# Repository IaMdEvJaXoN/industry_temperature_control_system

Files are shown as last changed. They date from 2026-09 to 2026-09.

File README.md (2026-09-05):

# Industrial Temperature Monitor

A complete, full-stack engineering project encompassing Firebase Real Time Database,custom printed circuit board (PCB) design, embedded C++ firmware ,simulations and a Flutter mobile application. 

The system provides closed-loop temperature monitoring and PWM hardware actuation, synchronized globally with sub-second latency via Firebase Realtime Database (RTDB).

## System Architecture

The project is structured as a monolithic repository integrating three distinct engineering domains:

    industry_temperature_control/
    ├── hardware/     # KiCad EDA (Schematics, PCB layout, Gerbers)
    ├── firmware/     # PlatformIO C++ (ESP32 logic, RTDB sync)
    ├── software/     # Flutter Mobile App (Clean Architecture, Riverpod, Hive)
    └── docs/         # System architecture, renders,wokwi simulation and media assets

### High-Level Topology
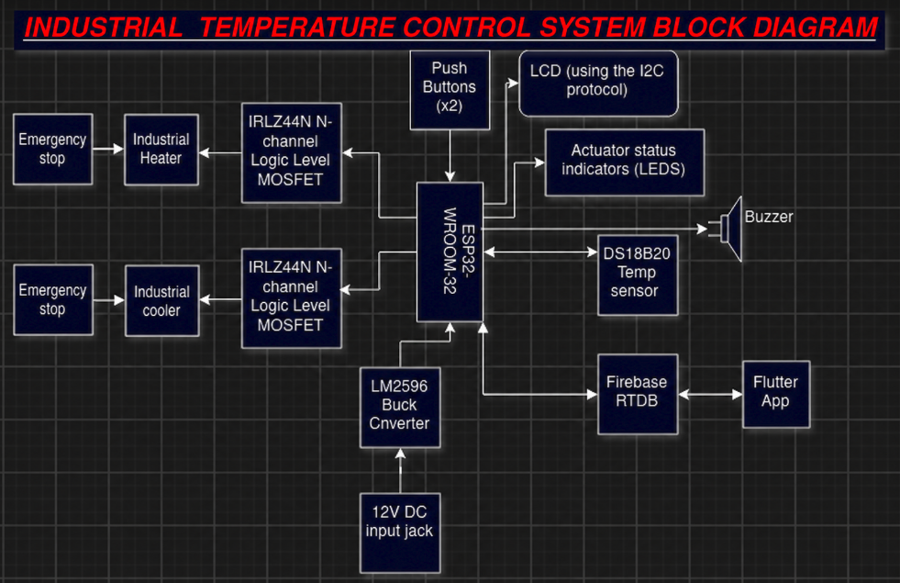
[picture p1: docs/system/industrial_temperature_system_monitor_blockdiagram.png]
System Block Diagram


*Validation: Real-time synchronization between the ESP32 hardware simulation and the Firebase RTDB backend.*
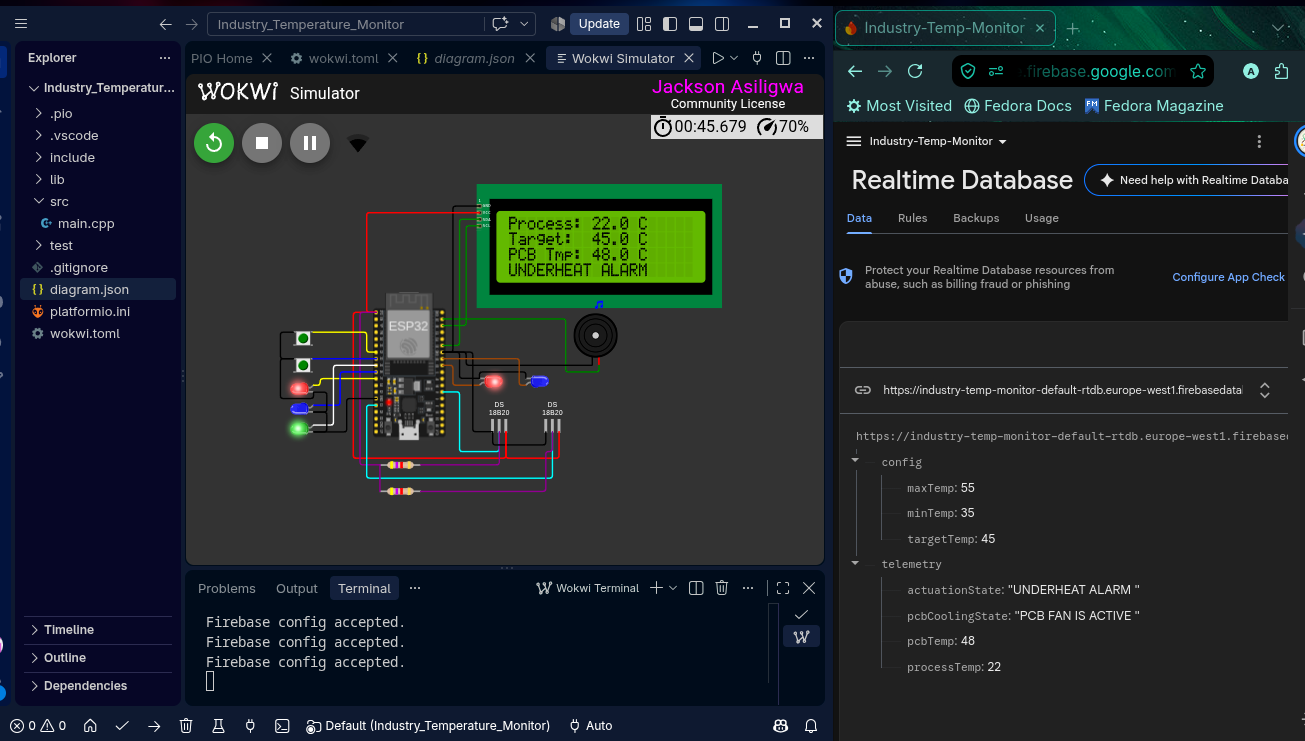
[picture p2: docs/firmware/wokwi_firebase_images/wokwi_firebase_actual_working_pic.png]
Wokwi Firebase Integration


---

## Hardware (KiCad)
The physical controller is a custom 2-layer PCB designed to handle both high-current 12V industrial loads and sensitive 3.3V digital logic.

**Core Specifications:**
* **Microcontroller:** DOIT ESP32 DEVKIT V1 -30 pin
* **Power Delivery Network (PDN):** 12V main input, regulated to 5V via an onboard LM2596 Buck Converter. High-current traces routed at 0.8mm width.
* **Logic Level Translation:** BOB-12009 bidirectional shifter (5V ↔ 3.3V) for I2C LCD communication.
* **Sensors & Actuators:** DS18B20 (1-Wire) digital temperature sensor, with MOSFET-driven PWM outputs for external fans and heating lamps.
* **Trace Topology:** 0.4mm logic lines routing across Top/Bottom copper planes with continuous ground pours for EMI shielding.

<p align="center">
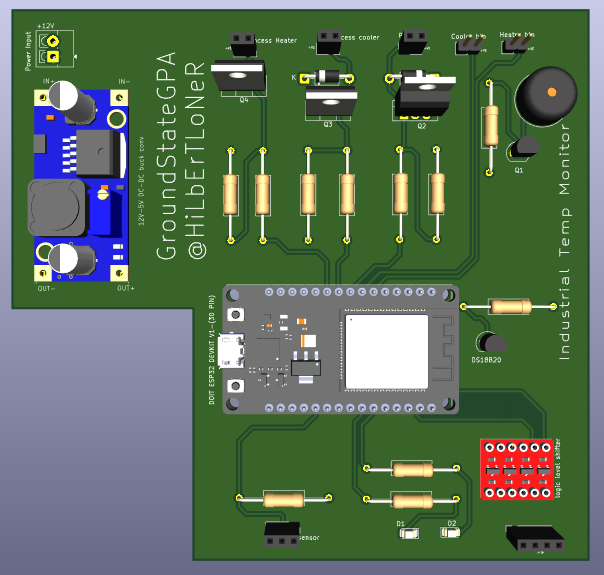
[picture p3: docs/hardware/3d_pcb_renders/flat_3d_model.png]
PCB Top Render
  
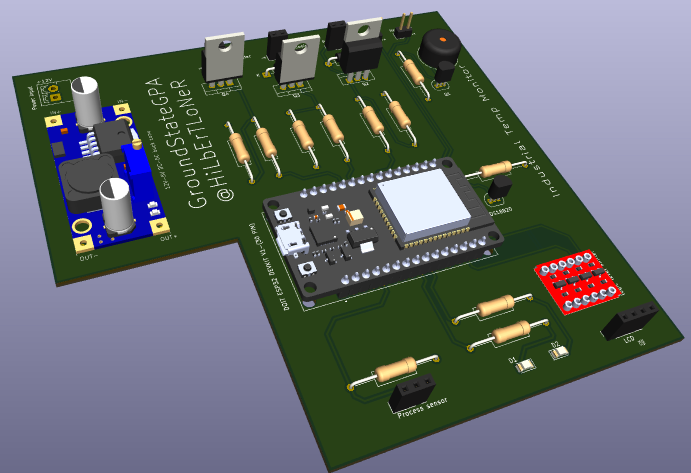
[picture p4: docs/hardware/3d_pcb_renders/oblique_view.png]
PCB Bottom Render
  
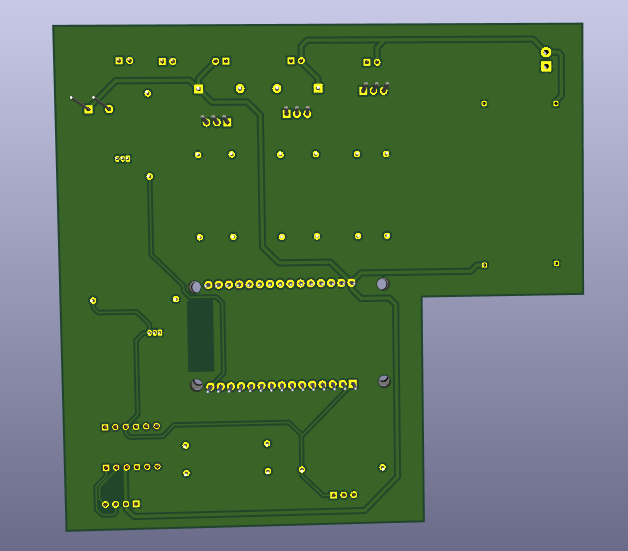
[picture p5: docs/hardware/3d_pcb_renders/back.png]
PCB Bottom Render
  
</p>

---

## Firmware (PlatformIO & Wokwi)
Written in C++ for the ESP32, the firmware manages real-time hardware interrupts, sensor polling, and network communication. 

**Key Features:**
* **Hardware Debouncing:** 200ms software debouncing for mechanical inputs.
* **Delta-Driven Telemetry:** Pushes raw JSON string payloads to the `/telemetry` RTDB node to minimize bandwidth (Tracking `processTemp`, `pcbTemp`, `actuationState`, and `pcbCoolingState`).
* **Config Listener:** Subscribes to the `/config` RTDB node to dynamically update operational setpoints (Target, Max, Min limits) pushed from the mobile app.

### Hardware Simulation
*A live capture of the logic execution in Wokwi:*

Hardware Simulation

---

## Software (Flutter Mobile App)
A mobile frontend built for performance.

**Technical Stack & Architecture:**
* **Architecture:** Strict Clean Architecture (Data, Domain, Presentation layers) utilizing Domain Use Cases to enforce boundary separation.
* **State Management:** Fully manual Riverpod (`AsyncNotifier` and `StreamProvider`), ensuring memory-safe stream disposal without code generation overhead.
* **Data Layer:** Direct Firebase RTDB streams (zero FCM/push notifications) for real-time telemetry, and Hive local storage mapping raw strings for history logging.
* **UI/UX:** Custom state-based routing, dynamic implicit animations driven by hardware states, and a Vantablack/charcoal design system.

<p align="center">
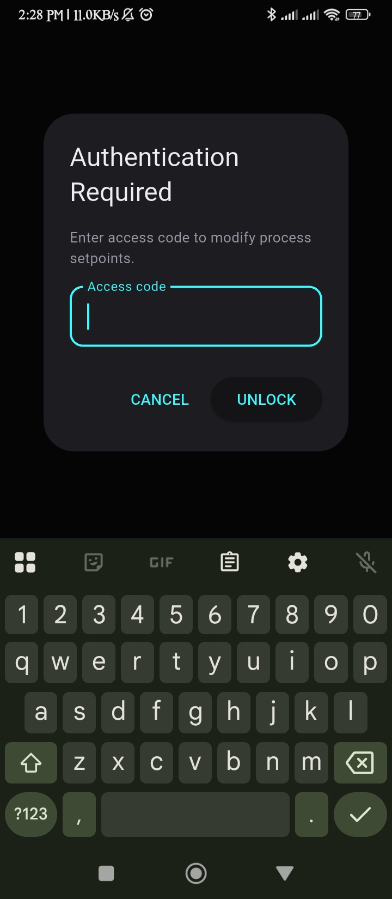
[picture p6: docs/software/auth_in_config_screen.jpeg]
Telemetry Dashboard
  
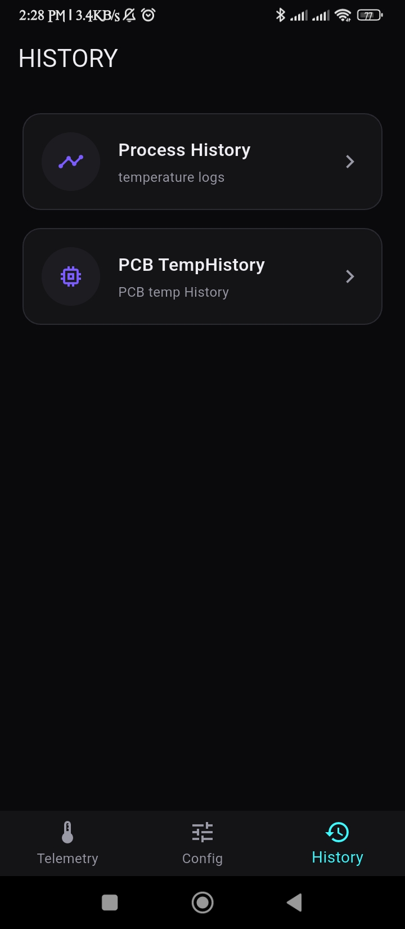
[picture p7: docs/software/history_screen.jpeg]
Configuration Hub
  
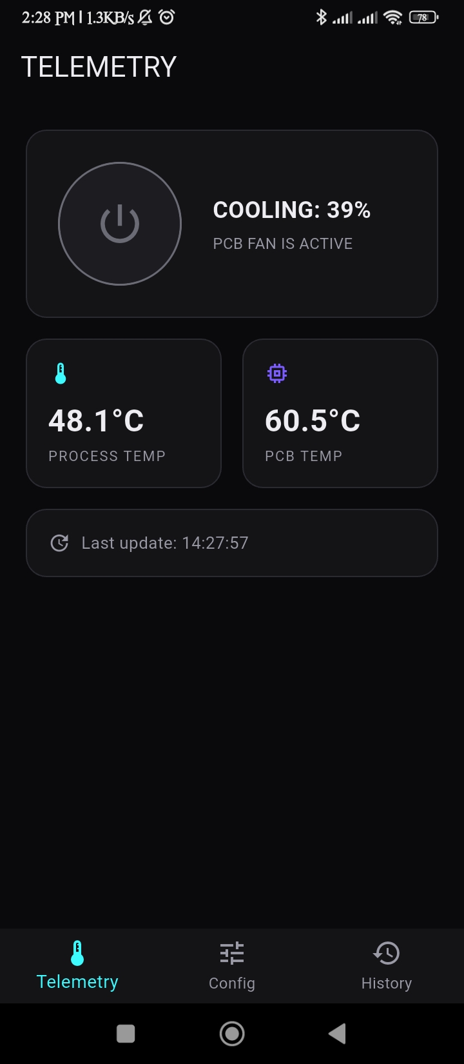
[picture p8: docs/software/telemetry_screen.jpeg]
History Logs
  
</p>

---

## Getting Started

**To view the Hardware:**
1. Install KiCad 10.0+.
2. Open `hardware/industry_temperature_control.kicad_pro`.

**To compile the Firmware:**
1. Open the `firmware/` directory in VS Code with the PlatformIO extension installed.
2. Create your firebase project and manually add your database URL and API_KEY-I removed mine for security purposes.
3. Build the environment to pull the required C++ dependencies.

**To run the Mobile App:**
1. Navigate to the `software/` directory.
2. Use your own firebase URL,the RTDB structure is already defined in the README.md of the software folder,you only need to create the Firebase project and create the nodes as they appear in the README.md in the software folder.
3. Run `flutterfire configure` command to configure your flutter app to the Firebase project.
4. Run `flutter pub get`.
5. Provide your own `google-services.json` (Android) from your Firebase console.
6. Run `flutter run`.

---
*Designed and engineered by Jackson Asiligwa*

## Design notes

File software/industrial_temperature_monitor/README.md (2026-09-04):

# Industrial Temperature Monitor

This flutter application is built for observing and configuring an industrial temperature control system. It presents live process and PCB temperatures, reports the controller's actuation state, and lets an authorised operator update temperature setpoints(the defined target,min and max operating point for a particular process e.g drying cereals or operating points for a machine like an industrial motor)  through Firebase Realtime Database.

## Features

- Live dashboard for process temperature, PCB temperature, controller actuation state, and PCB cooling status.
- Visual heating and cooling indicator with state-specific animation.
- Password-gated configuration form for target, minimum, and maximum temperatures.
- Input validation that requires `minimum < target < maximum` before writing configuration to the controller.
- Separate process and PCB history views backed by local Hive storage.
- Dark, operator-focused Material interface with Riverpod-managed state and stream lifecycles.

## How it works

The app subscribes to Firebase Realtime Database and maps the following nodes into the UI:

| Node | Fields | Purpose |
| --- | --- | --- |
| `/telemetry` | `processTemp`, `pcbTemp`, `actuationState`, `pcbCoolingState` | Live readings and controller state published by the ESP32. |
| `/config` | `target`, `min`, `max` | Operator setpoints written by the app after validation. |

The Firebase repository exposes these nodes as Dart streams. Riverpod providers consume the streams and rebuild only the affected screens. Hive is initialised at startup and supplies two local boxes for process and PCB history entries.

## Architecture

The app is built using flutter clean architecture principles.

## Technology

- Flutter and Dart (Dart SDK constraint: `^3.12.2`)
- `flutter_riverpod` for state management
- Firebase Core and Firebase Realtime Database for remote telemetry/configuration
- Hive/Hive Flutter for local history persistence
- Material Design

## Getting started

### Prerequisites

- A Flutter SDK compatible with the Dart constraint in [`pubspec.yaml`](pubspec.yaml)
- A Firebase Realtime Database configured with the schema above
- A controller or simulator that publishes telemetry to the configured database

### Run locally

```bash
flutter pub get
flutter run
```

The included FlutterFire configuration defines Firebase options for Android, iOS, macOS, web, and Windows. 

## Controller integration

An ESP32 or other controller must publish telemetry values that are numeric or numeric strings. Example:

```json
{
  "telemetry": {
    "processTemp": 72.4,
    "pcbTemp": 41.8,
    "actuationState": "COOLING",
    "pcbCoolingState": "FAN ON"
  },
  "config": {
    "target": 70.0,
    "min": 65.0,
    "max": 75.0
  }
}
```

## Security and operational notes

- The configuration gate is a demo convenience only. Its access code is embedded in the client and is **not** real access control.
- Do not rely on the app to protect process setpoints.THis is a demo app ,much better security configurations can be implemented.
- Firebase configuration files identify the project but do not implement database authorisation; verify database rules and authorised application identities separately.
- This application is a monitoring/configuration client, not a safety controller. Hardware failsafes, sensor validation, actuator limits, alarms, and emergency shutdown behaviour are implemented on the ESP32 side i.e in an actual industrial room.

Run the application against a controlled database/device before using it with real equipment. A successful UI connection or simulation does not establish electrical or thermal safety.

## License
The app is simply for development purposes,any contributions can be made.

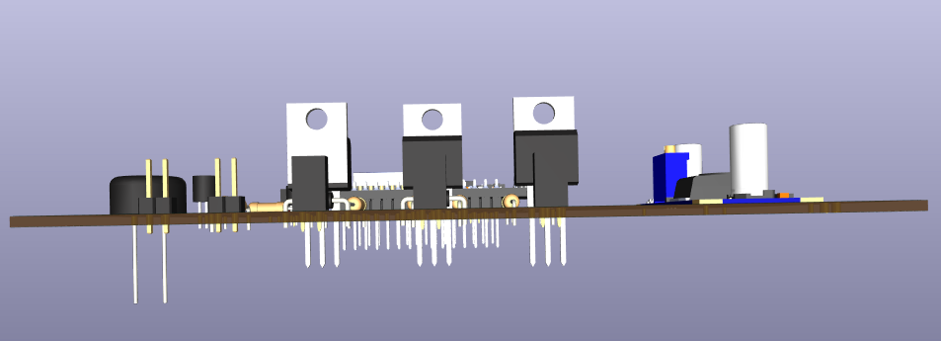
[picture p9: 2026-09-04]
docs/hardware/3d_pcb_renders/side_view.png

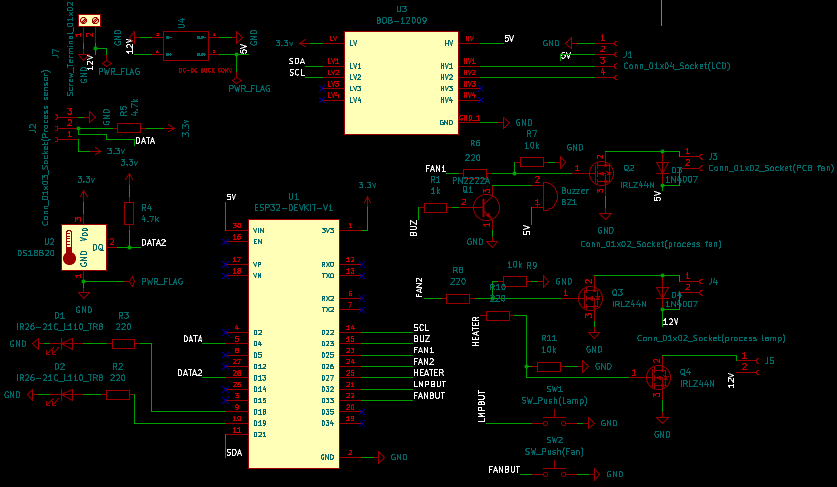
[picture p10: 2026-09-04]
docs/hardware/schematic/kicad_schematic.png

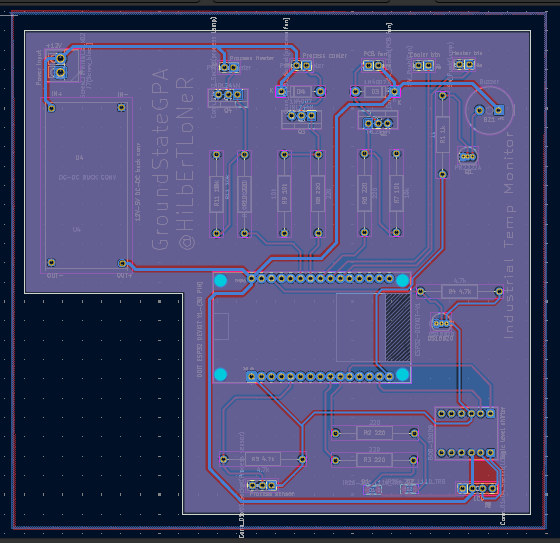
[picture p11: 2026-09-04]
docs/hardware/2d_pcb_images/back_copper_pcb.png

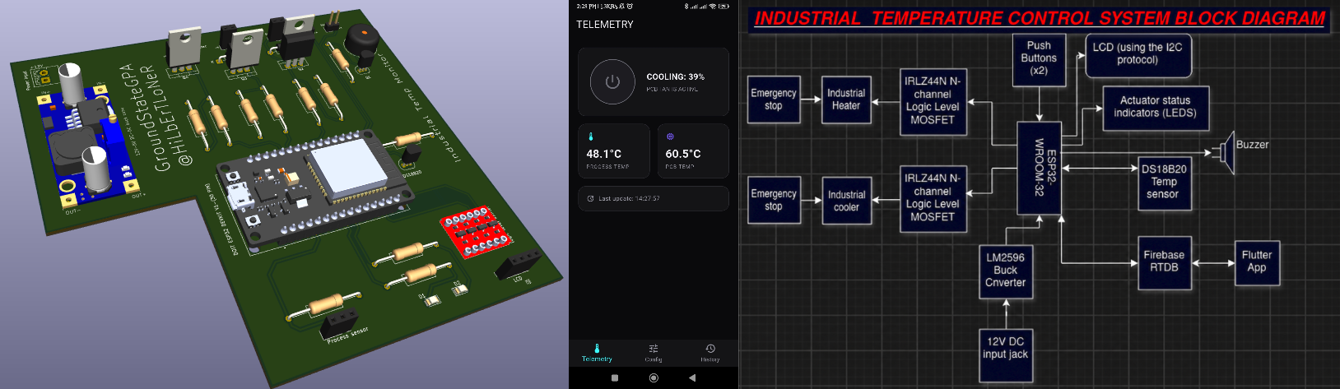
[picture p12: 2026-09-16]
docs/system/temp_monitor.png

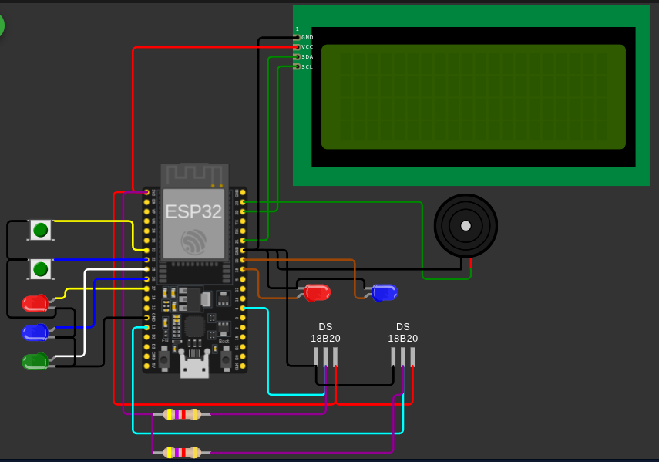
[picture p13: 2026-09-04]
docs/firmware/wokwi_firebase_images/wokwi_simulation.png

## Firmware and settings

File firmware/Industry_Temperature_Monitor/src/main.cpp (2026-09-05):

// LIBRARIES & DEPENDENCIES
#include <Arduino.h>             // The core Arduino framework functions(digitalWrite, millis, etc.)
#include <WiFi.h>                // Allows the ESP32 to connect to WIFI(local WiFi or Wokwi guest for simulation)
#include <Wire.h>                // I2C communication library (used to talk to the LCD screen)-enables the hardware communication
#include <OneWire.h>             // The low-level protocol required to talk to Dallas temperature sensors
#include <DallasTemperature.h>   // Translates the raw OneWire data into human-readable degree celsius values
#include <PID_v1.h>              // The PID engine is provided by this library.The calculus library that calculates smooth heating curves
#include <LiquidCrystal_I2C.h>   // Controls the 20x4 character display over I2C
#include <Firebase_ESP_Client.h> // The main Firebase library for cloud communication

// These are helper files included with the Firebase library to handle authentication tokens and JSON data payloads.
#include "addons/TokenHelper.h"
#include "addons/RTDBHelper.h"

// PIN DEFINITIONS
// We use #define here because it tells the compiler to replace the word
// before compiling. This uses ZERO bytes of runtime RAM.
#define PROCESS_TEMP_PIN 4 // Process temperature pin
#define PCB_FAN_TEMP 13    // Pin connected to the PCB temperature sensor
#define LCD_SDA 21         // I2C Data line
#define LCD_SCL 22         // I2C Clock line

#define LAMP_PWM_PIN 27        // Sends the pulsing 3.3V signal to the Lamp's MOSFET
#define PROCESS_FAN_PWM_PIN 26 // Sends the pulsing 3.3V signal to the Process Fan's MOSFET
#define PCB_FAN_PWM_PIN 25     // Sends the pulsing 3.3V signal to the PCB Fan's MOSFET

#define LAMP_LED 18   // Indicator LED showing if the lamp is on
#define FAN_LED 19    // Indicator LED showing if the fan is on
#define BUZZER_PIN 23 // The alarm buzzer

#define LAMP_BTN 32 // Manual override button for the lamp (Hardware Interrupt)
#define FAN_BTN 33  // Manual override button for the fan (Hardware Interrupt)

// WIFI / FIREBASE CONFIGURATION
#define WIFI_SSID "Wokwi-GUEST" // Network name
#define WIFI_PASSWORD ""        // Network password

#define API_KEY ""                                   // secret cloud password to the FIrebase RTDB
#define DATABASE_URL "" // The web address of your database in Firebase

// FIREBASE OBJECTS
// These background objects manage the complex internet connection.
FirebaseData fbdo;     // Holds the actual data being sent/received
FirebaseAuth auth;     // Manages your login credentials
FirebaseConfig config; // Holds the setup parameters (API key, URL)
bool signupOK = false; // A flag to confirm if we successfully connected to the cloud

// FreeRTOS MUTEX (The Memory Lock)
// Because Core 0 and Core 1 run at the exact same time, they might try to read/write
// the same temperature variable at the exact same microsecond, causing a race condition which
// might lead to unpredictable behaviours or even a crash.
// A Mutex is like a "key" to a room. A core must take the key, update the variable,
// and give the key back.
SemaphoreHandle_t dataMutex;

// SENSOR DATA (Shared Variables)
double currentTempProcess = 0.0;                       // The actual temperature of the measurand e.g machine operating temp
double currentTempPCB = 0.0;                           // The temperature inside your electronics box
char currentActuationState[21] = "STARTUP";            // The current state of the process
char currentPCBEnclosureActuationSate[21] = "STARTUP"; // To track if PCB temp sensor and fan are still working

// LOCAL CONTROL LIMITS
// 'constexpr' --> "Constant Expression".Like #define,it takes up zero RAM,
// but it is safer because it forces the compiler to check the math data type (double)
// These values can be changed from the flutter app via Firebase or via the Firebase console
constexpr double DEFAULT_TARGET_TEMP = 45.0; // What we want the temperature to be
constexpr double DEFAULT_MIN_TEMP = 35.0;    // The lowest safe temperature
constexpr double DEFAULT_MAX_TEMP = 55.0;    // The highest safe temperature

// Absolute failsafes: If Firebase glitches and tells the ESP32 to heat to 5000 degrees,
// these limits force the ESP32 to ignore the cloud and stay safe.
constexpr double ABSOLUTE_MIN_TEMP = 0.0;
constexpr double ABSOLUTE_MAX_TEMP = 100.0;

// The active limits being used by the PID loop. These can be changed by Firebase.
double targetTemp = DEFAULT_TARGET_TEMP;
double maxTemp = DEFAULT_MAX_TEMP;
double minTemp = DEFAULT_MIN_TEMP;

// SYSTEM STATE MACHINE
// An 'enum class' creates a custom list of strict physical states.
// Instead of messy "if/else" true/false flags, the system can only ever be in ONE of these states.
enum class ControlState
{
    STARTUP,
    SENSOR_FAULT,
    OVERHEAT_ALARM,
    UNDERHEAT_ALARM,
    MANUAL_LAMP,
    MANUAL_FAN,
    HEATING,
    DEAD_BAND,
    COOLING,
    NORMAL
};

// Start the system in the STARTUP state
ControlState controlState = ControlState::STARTUP;

// Flags to track if the physical sensors are actually connected and working
bool processSensorOK = false;
bool pcbSensorOK = false;

// FIREBASE TELEMETRY TRACKERS
double lastSentTemp = 0.0;        // The last process temperature we uploaded
bool hasSentTemp = false;         // Tracks if we have uploaded process temp at least once
double lastSentPCBTemp = 0.0;     // Lats uploaded PCB temerature
bool hasSentPCBTemp = false;      // Tracks if PCB temp has been uploaded to Firebase RTDB at least once
char prevActuationState[21] = ""; // Tracks actuation status
bool hasSentActuationState = false;
char prevPCBTempMonitorState[21] = "";

// MANUAL OVERRIDE FLAGS (Hardware Interrupts)
// 'volatile' is critical here. It tells the compiler that a variable is changed by an
// action outside the normal loop. It should not be cached but rather it should be fetched from RAM every time.
volatile bool manualLampOverride = false;
volatile bool manualFanOverride = false;

// Timestamps to prevent "Button Bounce"(metal contacts vibrating)
volatile unsigned long lastLampBtnTime = 0;
volatile unsigned long lastFanBtnTime = 0;

// HARDWARE OBJECTS
OneWire oneWire(PROCESS_TEMP_PIN);         // Sets up the physical wire on GPIO 4
DallasTemperature sensorProcess(&oneWire); // Connects the Dallas library to that physical wire
OneWire oneWirePCB(PCB_FAN_TEMP);          // sets the physical wire on GPIO 13
DallasTemperature sensorPCB(&oneWirePCB);  // Connetcs the dallas library to #define PCB_TEMP_PIN 13that physical wire

LiquidCrystal_I2C lcd(0x27, 20, 4); // Sets up a 20-column, 4-row LCD at I2C address 0x27

// PID CONTROLLER SETUP
double pidInput = 0.0;                    // What the temperature is right now
double pidOutput = 0.0;                   // What the heater power should be (0-255)
double pidSetPoint = DEFAULT_TARGET_TEMP; // What we want the temperature to be

// PID Tuning values
// Kp (Proportional gain) - How hard to push based on current error.
// Ki (Integral gain) - Looks at past errors to fix steady-state drift.
// Kd (Derivative gain) - Looks at future trends to slow down and prevent overshoot.
double Kp = 25.0, Ki = 5.0, Kd = 1.0;

// Create the PID object and link it to the memory addresses (&) of our variables
PID lampPID(&pidInput, &pidOutput, &pidSetPoint, Kp, Ki, Kd, DIRECT);

// CONFIGURATION
constexpr uint32_t PWM_FREQ = 5000;   // Flashes the MOSFET 5,000 times per second
constexpr uint8_t PWM_RESOLUTION = 8; // 8-bit math = 2^8 = 256 steps (0 to 255)
constexpr uint32_t PWM_MAX = 255;     // Maximum power

// ESP32 v3.x API uses independent channels for hardware timers(ESP32 has 16 timers-0 to 15)
// We assign a unique hardware channel to every single output.
constexpr int LAMP_CHANNEL = 0;
constexpr int PROCESS_FAN_CHANNEL = 1;
constexpr int PCB_FAN_CHANNEL = 2;
constexpr int LAMP_LED_CHANNEL = 3;
constexpr int FAN_LED_CHANNEL = 4;

// PCB FAN HYSTERESIS
// Hysteresis prevents rapid on/off switching. The fan turns on at 40C,
// but won't turn off until it cools all the way down to 38C.
constexpr double PCB_FAN_ON_TEMP = 40.0;
constexpr double PCB_FAN_OFF_TEMP = 38.0;
bool pcbFanActive = false; // Tracks if the PCB cooling fan is currently spinning

// HELPER FUNCTION-MAP DOUBLE
// The standard Arduino map() function only works with integers (e.g., 45, 46).
// This custom function allows us to map precise decimals (e.g., 45.2 to a smooth fan speed).
long mapDouble(double x, double in_min, double in_max, long out_min, long out_max)
{
    if (in_max <= in_min)
    {
        return out_min;
    } // Prevent divide-by-zero crash
    // Standard linear interpolation math
    double result = (x - in_min) * (double)(out_max - out_min) / (in_max - in_min) + out_min;
    return (long)result;
}

// Helper function to clamp values in the required range.
// Forces a number to stay within a specific range to prevent math overflow errors.
double clampDouble(double value, double minimum, double maximum)
{
    if (value < minimum)
        return minimum;
    if (value > maximum)
        return maximum;
    return value;
}

// FIREBASE CONFIGURATION VALIDATION
// Checks the numbers downloaded from the internet to make sure they are safe
// before applying them to the hardware.
bool validTemperatureConfiguration(double newMin, double newTarget, double newMax)
{
    // Check if the numbers are physically impossible/dangerous
    if (newMin < ABSOLUTE_MIN_TEMP || newMin > ABSOLUTE_MAX_TEMP)
        return false;
    if (newTarget < ABSOLUTE_MIN_TEMP || newTarget > ABSOLUTE_MAX_TEMP)
        return false;
    if (newMax < ABSOLUTE_MIN_TEMP || newMax > ABSOLUTE_MAX_TEMP)
        return false;

    // Logical check: Min must be lowest, Max must be highest.
    if (!(newMin < newTarget && newTarget < newMax))
    {
        return false;
    }
    return true; // The cloud data is safe to use!
}

// BUTTON INTERRUPTS (Hardware level)
// IRAM_ATTR forces this code into the fast Instruction RAM. It pauses whatever the CPU is doing
// the exact microsecond the button is pressed.
// It's an interrupt so it should be executed very fast hence should be stored in IRAM rather than
// in flash memory which would take time.
// To avoid the GURU meditation error
void IRAM_ATTR handleLampBtn()
{
    unsigned long currentTime = millis();
    // Debounce: Only accept a press if 200ms have passed since the last one
    if (currentTime - lastLampBtnTime > 200)
    {
        manualLampOverride = !manualLampOverride; // Toggle the state
        // Safety: If we turn the Lamp on manually, force the Fan off manually.
        if (manualLampOverride)
        {
            manualFanOverride = false;
        }
        lastLampBtnTime = currentTime;
    }
}

void IRAM_ATTR handleFanBtn()
{
    unsigned long currentTime = millis();
    if (currentTime - lastFanBtnTime > 200)
    {
        manualFanOverride = !manualFanOverride;
        // Safety: If we turn the Fan on manually, force the Lamp off manually.
        if (manualFanOverride)
            manualLampOverride = false;
        lastFanBtnTime = currentTime;
    }
}

// OUTPUT CONTROL HELPERS
// These tiny functions make the main code easier to read.
void setLampPWM(uint8_t duty) { ledcWrite(LAMP_CHANNEL, duty); }
void setProcessFanPWM(uint8_t duty) { ledcWrite(PROCESS_FAN_CHANNEL, duty); }
void setPCBfanPWM(uint8_t duty) { ledcWrite(PCB_FAN_CHANNEL, duty); }
void setLampLED(uint8_t duty) { ledcWrite(LAMP_LED_CHANNEL, duty); }
void setFanLED(uint8_t duty) { ledcWrite(FAN_LED_CHANNEL, duty); }

// A panic function to shut everything down safely
void allActuatorsSafe()
{
    setLampPWM(0);
    setProcessFanPWM(0);
    setPCBfanPWM(0);
    setLampLED(0);
    setFanLED(0);
    digitalWrite(BUZZER_PIN, LOW);
}

// CORE 0(The protocol core) - FIREBASE CLOUD TASK (Networking)
// This entire block runs on one CPU core,completely independent of the hardware.
void TaskCloudSync(void *pvParameters)
{
    Serial.println("Cloud task started.");

    // 1. Connect to the local router
    WiFi.begin(WIFI_SSID, WIFI_PASSWORD);
    while (WiFi.status() != WL_CONNECTED) // This loop runs until there's a connection
    {
        Serial.println("Waiting for WiFi...");
        // Yield the CPU to the operating system for 500ms so it doesn't freeze
        vTaskDelay(pdMS_TO_TICKS(500));
    }
    Serial.println("WiFi connected.");

    // 2. Configure Firebase Credentials
    config.api_key = API_KEY;
    config.database_url = DATABASE_URL;

    // Try to log in securely
    // Anonymous signup
    if (Firebase.signUp(&config, &auth, "", ""))
    {
        signupOK = true;
        Serial.println("Firebase auth successful.");
    }
    else
    {
        Serial.println("Firebase auth failed.");
    }

    config.token_status_callback = tokenStatusCallback; // Provided by the addons/TokenHelper included at the top of this file
    Firebase.begin(&config, &auth);
    Firebase.reconnectWiFi(true); // Auto-reconnect if router reboots

    // 3. The Infinite Cloud Loop
    for (;;)
    {
        // Only attempt internet comms if we are successfully logged in
        if (Firebase.ready() && signupOK)
        {

            double newTarget, newMin, newMax;
            bool targetOK = false, minOK = false, maxOK = false;

            // DOWNLOADING DATA FROM CLOUD
            // Target Temp
            if (Firebase.RTDB.getDouble(&fbdo, "/config/targetTemp"))
            {
                newTarget = fbdo.to<double>();
                targetOK = true;
            }
            // Min Temp
            if (Firebase.RTDB.getDouble(&fbdo, "/config/minTemp"))
            {
                newMin = fbdo.to<double>();
                minOK = true;
            }
            // Max Temp
            if (Firebase.RTDB.getDouble(&fbdo, "/config/maxTemp"))
            {
                newMax = fbdo.to<double>();
                maxOK = true;
            }

            // If we successfully receive all the three numbers
            if (targetOK && minOK && maxOK)
            {
                // run them through the safety check function.
                if (validTemperatureConfiguration(newMin, newTarget, newMax))
                {
                    // if safe,take the Mutex key, update the core variables, drop the key.
                    xSemaphoreTake(dataMutex, portMAX_DELAY);
                    targetTemp = newTarget;
                    minTemp = newMin;
                    maxTemp = newMax;
                    xSemaphoreGive(dataMutex);
                    Serial.println("Firebase config accepted.");
                }
                else
                {
                    Serial.println("Invalid Firebase config rejected.");
                }
            }

            // UPLOADING DATA TO CLOUD
            double processTempToSend;
            double pcbTempToSend;
            char processStatusToSend[21];
            char pcbTempMonitorStateToSend[21];

            // Take the Mutex key to safely read the current temperature from Core 1
            xSemaphoreTake(dataMutex, portMAX_DELAY);
            processTempToSend = currentTempProcess;
            pcbTempToSend = currentTempPCB;
            strlcpy(processStatusToSend, currentActuationState, sizeof(processStatusToSend));
            strlcpy(pcbTempMonitorStateToSend, currentPCBEnclosureActuationSate, sizeof(pcbTempMonitorStateToSend));
            bool localProcessOK = processSensorOK; // Check if the sensor is actually working
            bool localPcbOK = pcbSensorOK;
            xSemaphoreGive(dataMutex);

            // Delta-Driven Telemetry - Only upload if the sensor works and the temperature
            // has changed by more than 0.5 degrees since the last time we uploaded.
            // This saves database bandwidth.
            // I am on free plan so i dont want to hit the firebase limits by sending data frequently.
            if (localProcessOK)
            {
                if (!hasSentTemp || abs(processTempToSend - lastSentTemp) > 0.5)
                {
                    if (Firebase.RTDB.setDouble(&fbdo, "/telemetry/processTemp", processTempToSend))
                    {
                        lastSentTemp = processTempToSend; // Remember what we just sent
                        hasSentTemp = true;
                    }
                }
                if (!hasSentActuationState || (strcmp(processStatusToSend, prevActuationState) != 0))
                {
                    if (Firebase.RTDB.setString(&fbdo, "/telemetry/actuationState", processStatusToSend))
                    {
                        strlcpy(prevActuationState, processStatusToSend, sizeof(prevActuationState));
                        hasSentActuationState = true;
                    }
                }
            }

            if (localPcbOK)
            {
                if (!hasSentPCBTemp || abs(pcbTempToSend - lastSentPCBTemp) > 0.5)
                {
                    if (Firebase.RTDB.setDouble(&fbdo, "/telemetry/pcbTemp", pcbTempToSend))
                    {
                        lastSentPCBTemp = pcbTempToSend;
                        hasSentPCBTemp = true;
                    }

                    if (strcmp(pcbTempMonitorStateToSend, prevPCBTempMonitorState))
                    {
                        if (Firebase.RTDB.setString(&fbdo, "/telemetry/pcbCoolingState", pcbTempMonitorStateToSend))
                        {
                            strlcpy(prevPCBTempMonitorState, pcbTempMonitorStateToSend, sizeof(prevPCBTempMonitorState));
                        }
                    }
                }
            }
            else
            {
                char pcbEnclosureTempSensorError[21] = "PCB TEMP SENSOR ERR ";
                if (Firebase.RTDB.setString(&fbdo, "/telemetry/pcbCoolingState", pcbEnclosureTempSensorError))
                {
                    strlcpy(prevPCBTempMonitorState, pcbEnclosureTempSensorError, sizeof(prevPCBTempMonitorState));
                }
            }
        }
        // Pause the Cloud task for 2 seconds. FreeRTOS puts it to sleep.
        vTaskDelay(pdMS_TO_TICKS(2000));
    }
}
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
void loop()
{
    // Because we created our own infinite Task loops above, this default Arduino loop
    // is completely useless. We delete it to free up the RAM.
    vTaskDelete(NULL);
}

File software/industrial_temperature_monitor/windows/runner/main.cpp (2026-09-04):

#include <flutter/dart_project.h>
#include <flutter/flutter_view_controller.h>
#include <windows.h>

#include "flutter_window.h"
#include "utils.h"

int APIENTRY wWinMain(_In_ HINSTANCE instance, _In_opt_ HINSTANCE prev,
                      _In_ wchar_t *command_line, _In_ int show_command) {
  // Attach to console when present (e.g., 'flutter run') or create a
  // new console when running with a debugger.
  if (!::AttachConsole(ATTACH_PARENT_PROCESS) && ::IsDebuggerPresent()) {
    CreateAndAttachConsole();
  }

  // Initialize COM, so that it is available for use in the library and/or
  // plugins.
  ::CoInitializeEx(nullptr, COINIT_APARTMENTTHREADED);

  flutter::DartProject project(L"data");

  std::vector<std::string> command_line_arguments =
      GetCommandLineArguments();

  project.set_dart_entrypoint_arguments(std::move(command_line_arguments));

  FlutterWindow window(project);
  Win32Window::Point origin(10, 10);
  Win32Window::Size size(1280, 720);
  if (!window.Create(L"industrial_temperature_monitor", origin, size)) {
    return EXIT_FAILURE;
  }
  window.SetQuitOnClose(true);

  ::MSG msg;
  while (::GetMessage(&msg, nullptr, 0, 0)) {
    ::TranslateMessage(&msg);
    ::DispatchMessage(&msg);
  }

  ::CoUninitialize();
  return EXIT_SUCCESS;
}
